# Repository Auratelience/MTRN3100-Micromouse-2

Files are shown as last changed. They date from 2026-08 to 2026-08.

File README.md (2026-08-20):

# MTRN3100 Micromouse

A micromouse that can either be told the maze or made to explore it. Told: an
overhead photo of the deck goes in, a collision-checked path in the firmware's
own `Segment` alphabet comes out, and the robot drives it while localising
against a map exported from the same photo. Explore: the robot is given a start
cell and a goal, maps the maze with its three range sensors, then plans a route
over what it found and races it.

```
                    path-planning/                     firmware/
   maze photo  ->   photo -> lattice -> map        ->  maze_map.h   ->  Arduino
   (.png/.jpg)      map   -> Dubins RRT* -> path        maze_path.h      Nano R4

                                    firmware-sim/
                          the same two headers, driven against a
                          line-by-line Python port of the sketch
```

Six directories, each with its own README:

| directory | what it is | language |
| --- | --- | --- |
| [`firmware/`](firmware/) | the robot. `micromouse.ino` plus the header-only libraries it is built from | C++17, Arduino |
| [`firmware-sim/`](firmware-sim/) | `micromouse.ino`'s control loop with a simulated robot underneath it, and 257 tests over it | Python, stdlib only |
| [`path-planning/`](path-planning/) | photo in, `maze_map.h` and `maze_path.h` out | Python + OpenCV/NumPy/SciPy, via `uv` |
| [`scripts/`](scripts/) | every entry point: `build.sh` compiles the sketch, `build_maze.sh` runs the photo-to-headers pipeline, `export_splash.py` turns the splash art into a bitmap | zsh, Python |
| [`hardware/`](hardware/) | CAD for the printed chassis and the maze wall panels, and the OLED splash art | Bambu Studio, Grasshopper, Aseprite |
| [`notes/`](notes/) | course handouts and working notes. Nothing here is read by any code | PDF, JPEG |

Both scripts take `--help`, run from any directory, and derive their paths from
the repo root rather than the caller's cwd.

## The robot

An Arduino Nano R4 (`arduino:renesas_uno:nanor4`) driving a two-wheel
differential base, with everything but the motors and encoders on one I2C bus.

| part | detail | where it is described |
| --- | --- | --- |
| 2 × DC motor + quadrature encoder | 700 CPR, 31.4 mm effective wheel diameter, 92.5 mm axle | `firmware/micromouse/motor.h`, `constants.h` |
| DRV8835 H-bridge | PWM on `xEN`, direction on `xPH` | `pins.h` |
| MPU6050 IMU | gyro Z only; accelerometer measured and left unused | `imu.h`, `observers.h` |
| 3 × VL6180X ToF | front / left / right, addresses `0x30`–`0x32`, re-addressed at boot over their GPO pins | `lidar.h` |
| SSD1306 OLED 128×64 | a splash through bring-up, then one screen for every task: the map on the left, the run's numbers on the right | `oledDisplay.h`, `oledScreen.h`, `oledSplash.h` |

Pin assignment lives in one place, `firmware/micromouse/pins.h`. Every tunable
number lives in one place, `firmware/micromouse/constants.h`, and each one
carries the reasoning for its value.

The maze is the full-size standard: 180 mm cells, 12 mm panels and posts.

## Getting started

### Flash the robot

Open `firmware/micromouse/micromouse.ino` in the Arduino IDE, or:

```sh
./compile.sh                        # build into firmware/build, ~15s (--help for options)
./compile.sh --flash                # ...and upload it to the connected board, ~11s more
```

`--flash` finds the port by asking `arduino-cli` which one has a board matching
the FQBN on it, so nothing has to be hardcoded; pass `--port /dev/cu.usbmodemXXXX`
to override it. The port is resolved *before* the build, so an unplugged board
fails immediately instead of after a full compile.

`./compile.sh` forwards to `./scripts/build.sh`.

Libraries: Embedded Template Library, Adafruit SSD1306 (and Adafruit GFX),
VL6180X. Which task the sketch builds is one `#define TASK` near the top of
`micromouse.ino` — see [`firmware/README.md`](firmware/README.md) for what each
one does.

### Plan a maze

```sh
./scripts/build_maze.sh 5.png --from 1,1 --to 3,3   # overlay on screen, headers installed
./scripts/build_maze.sh 5.png --no-install          # ...or leave the firmware alone
```

This is the only supported way to produce the pair, because the map and the path
have to be exported against the *same* start pose or the robot localises against
a map offset from the path it is driving. The wrapper exists to enforce that.
Details in [`path-planning/README.md`](path-planning/README.md).

The first run lets `uv` build the environment from `path-planning/pyproject.toml`
(Python ≥ 3.14, OpenCV, NumPy, SciPy).

### Drive it without a robot

```sh
cd firmware-sim
python3 -P run.py --viz --open                # watch it drive the installed headers
python3 -P run.py task34                      # a retained TASK 3.x regression scenario
```

[`firmware-sim/README.md`](firmware-sim/README.md) covers the arguments and what
the sim is and is not a port of.

### Run the tests

The sim's 257 tests, from the repo root:

```sh
python3 -P -c "
import importlib, pathlib, sys, unittest
sys.path.insert(0, '.')
suite = unittest.TestSuite()
for p in sorted(pathlib.Path('firmware-sim/tests').glob('test_*.py')):
    suite.addTests(unittest.defaultTestLoader.loadTestsFromModule(
        importlib.import_module('firmware-sim.tests.' + p.stem)))
sys.exit(not unittest.TextTestRunner().run(suite).wasSuccessful())
"
```

and the planner's own checks:

```sh
cd path-planning
uv run python selftest.py            # Dubins, segments, world, planner
uv run python selftest.py --image    # ...and the CV pass, which needs mazes/1.png
```

No maze photo is tracked, so the `--image` pass needs one supplied — see
[`path-planning/mazes/README.md`](path-planning/mazes/README.md).

**Why `-P`, and why not `unittest discover`.** `firmware-sim/types.py` mirrors
the firmware's `types.h` and so shadows the standard library's `types` module
whenever its directory lands on `sys.path` — which is exactly what running a
script from that directory does. `-P` (or `PYTHONSAFEPATH=1`) keeps it off.
`python3 -m unittest discover -s . -t ..` additionally needs the loader to
accept a namespace package: the directory is called `firmware-sim`, a hyphen is
not a legal identifier, and there is no `__init__.py` to fall back on. CPython
3.11 through 3.14 refuse it with *Start directory is not importable*, hence the
explicit loader above.

## Conventions that cross directory boundaries

**Two frames, two handednesses.** The map is in image convention — +x east, +y
south, origin at the lattice corner — and is left-handed. The robot's frame is
right-handed: **x forward, y left**, theta CCW, origin wherever odometry was last
reset. `path-planning/segments.py::to_firmware` mirrors between them and flips
every `Left`/`Right` as it goes. Anything under `firmware/` is in the robot
frame; anything under `path-planning/` is in the map frame until it is emitted.

The same convention carries into cells: `Direction` in `types.h` has North
stepping +x and West stepping +y, so a route `MazeMapper` produces feeds
`PSPlanner` with no axis or sign fixup in between.

**Units are mm, radians and seconds,** everywhere, including inside the
generated headers.

**`maze_map.h`, `maze_path.h` and `splash_screen.h` are generated.** Do not
hand-edit them; the `snake_case` name is the signal. Re-run `build_maze.sh` for
the first two, which each keep the previous copy as `.bak` beside it: `maze_map.h`
records the photo, the lattice fit RMS and the start pose it was exported
against; `maze_path.h` records the start and goal cells, the turn radius and the
same frame note. `splash_screen.h` is the OLED logo, and `build.sh --flash`
re-exports it from `hardware/Splashscreen.png` on its own.

**Numbers that appear in two languages are mirrored, not shared.**
`firmware/micromouse/constants.h`, `firmware-sim/constants.py` and the geometry
constants in `path-planning/maze_map.py` carry the same values by hand. When the
C++ and the Python disagree, the C++ is right — that is the premise the sim is
built on.

## Known divergences

Real, verified, and worth knowing before trusting a run:

* **The axle offset differs between the firmware and the planner.**
  `AXLE_DIST_FROM_CENTRE` is `20` mm in `firmware/micromouse/constants.h` and in
  `firmware-sim/constants.py`; `AXLE_OFFSET_MM` in `path-planning/rrt_star.py`
  is `25.0`. The planner is therefore clearing corners for a body 5 mm further
  ahead of the axle than the firmware believes it has, which is conservative in
  the direction that matters but means the two are not mirroring the same
  number. The turn-radius bands quoted in `path-planning/README.md` are derived
  from the 25.
* **The sim runs a pose correction gain of `0.2` where the sketch passes `0.1`.**
  Both `task42.h` and `task43.h` build `SensorFusion sf(obs_v, obs_p, 0.1)`;
  `firmware-sim` keeps the `FusionWeights::PoseCorrectionGain` default of `0.2`.
  So a lidar fix is folded in twice as fast in the sim as on the robot. See
  `firmware-sim/README.md`.
* **`FrontLidarObserver` ignores its 57 mm mount offset**
  (`LIDAR_MOUNT_FRONT_X`), in both copies. It writes `pose.x =
  -getReading(Front)`, so the pose it reports is 57 mm short. Fine as a relative
  wall-distance measurement, wrong as a pose. See `firmware-sim/README.md`.
* **No maze photo is tracked.** `.gitignore` excludes `*.png` and `*.jpg`, so
  `path-planning/mazes/` arrives empty from a fresh clone while several scripts
  default to a photo in it — `maze_demo.py` to `mazes/4.png`, and
  `export_map.py`, `bench.py` and `selftest.py --image` to `mazes/1.png`. Supply
  your own and pass it explicitly. See
  [`path-planning/mazes/README.md`](path-planning/mazes/README.md).
* **`scripts/build.sh` still advertises a `lidar` target.** It points at
  `firmware-ds/lidar`, a bring-up sketch that has been deleted from the repo, so
  `./scripts/build.sh lidar` fails. `micromouse` is the only target that builds.

---

MTRN3100 micromouse project — Zimmy Levi (z5587840).

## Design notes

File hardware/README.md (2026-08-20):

# hardware

CAD for the things that get printed: the robot's chassis plate, and the maze wall
panels the deck is built from. Nothing here is built, generated or read by any
code in this repository — it is kept alongside the source so the chassis that the
constants in `firmware/micromouse/constants.h` describe does not live on
somebody's laptop.

| file | format | tracked | opens with |
| --- | --- | --- | --- |
| `Micromouse Lower Frame v2.3mf` | 3MF, Bambu Studio project (~73 KB) | yes | Bambu Studio, Orca Slicer; the mesh alone in any slicer or CAD tool |
| `Wall.3mf` | 3MF, Bambu Studio project (~118 KB) | yes | as above |
| `Wall.gh` | Grasshopper definition (~15 KB) | yes | Grasshopper, inside Rhinoceros |
| `Wall.stl`, `Wall-nolegs.stl` | STL meshes | **no** — `.gitignore` excludes `*.stl` | anything |

Both `.3mf` files are slicer *projects*, not bare meshes: they carry the plate
layout and the print profile as well as the geometry. Re-slice against your own
printer before sending either anywhere.

A `.3mf` is a zip, so the geometry can be pulled out without a slicer:

```sh
unzip -o "Micromouse Lower Frame v2.3mf" -d frame/   # 3D/Objects/*.model is the mesh
```

## Lower frame

The printed chassis plate the motors, board and sensor mounts bolt to. Version 2.

One object, 2160 vertices, bounding box ≈ 82.2 × 84.2 × 24.5 mm. Saved profile:
**Bambu Lab X1E, 0.4 mm nozzle, Bambu PLA Basic, 0.2 mm layers**.

## Wall

The maze panels. One wall part, tiled as 16 instances across three plates, so a
run of the project prints a batch rather than a single piece. The part's mesh
spans 183 × 183 × 85 mm — a cell-pitch footprint, matching the 180 mm cells and
12 mm panels in `constants.h`. Saved profile: **Bambu Lab X1E, 0.4 mm nozzle,
generic PLA, 0.28 mm layers** — a coarser layer height than the frame, since
these are bulk structural prints.

`Wall.gh` is the Grasshopper definition the geometry came from, so the panels are
parametric: change the pitch or the height there and re-bake rather than editing
a mesh. It needs Rhino, and it is binary, so git cannot merge it.

`Wall.stl` is the baked mesh and `Wall-nolegs.stl` the same panel without its
feet. Neither is tracked — re-export them from `Wall.gh` or `Wall.3mf`.

Neither the `.3mf` nor the `.gh` has a plain-text representation, so git cannot
merge any of this. If two people need to change one, take turns.

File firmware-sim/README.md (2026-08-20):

# firmware-sim

`micromouse.ino`'s control loop, with a simulated robot underneath it.

```
python3 run.py                            # drive the installed maze_path.h
python3 run.py --viz --open               # ...and watch it
python3 run.py task34                     # a retained TASK 3.x regression scenario
python3 run.py --plan 5 --from 1,1 --to 4,6   # plan a fresh path first, then drive it
```

There are 257 tests. `unittest discover` cannot load them — see the note below —
so the root [`README.md`](../README.md#run-the-tests) carries the explicit loader
to run them with.

Stdlib only. `--plan` is the one exception and it runs path-planning in
path-planning's own uv environment, not this one.

Two portability notes, both consequences of the directory layout rather than of
the sim. `types.py` mirrors `types.h` and so shadows the standard library's
`types` module on any interpreter that has not already imported it by the time
this directory reaches `sys.path` — if `run.py` dies importing `enum`, run it as
`python3 -P run.py` (or set `PYTHONSAFEPATH=1`). And `unittest discover` has to
accept a namespace package to name a directory with a hyphen in it: CPython 3.11
through 3.14 do not, and answer *Start directory is not importable*. The root
[`README.md`](../README.md#run-the-tests) carries an explicit loader that runs
all 257 tests without either problem.

## What is a port and what is not

Every module named after a header is a line-by-line port of it, method names and
all, so the two can be diffed by eye. **When they disagree, the header is
right** — that is the whole point. Where a port deliberately departs from the
sketch it is a *configuration* choice, never a behavioural one, and each is
listed under [Where the sim departs from the
sketch](#where-the-sim-departs-from-the-sketch).

| module | mirrors | notes |
| --- | --- | --- |
| `constants.py` | `constants.h` | verbatim; derived values stay derived |
| `types.py` | `types.h` | `Segment`, and the `Obstacle`/`Map` layer `LidarObserver` casts into. No `trig<>` LUTs, no `RingBuffer` |
| `kinematics.py` | `kinematics.h` | |
| `control.py` | `control.h` | `PID`, `MotionController` |
| `planners.py` | `planners.h` | all five planners |
| `observers.py` | `observers.h` | including `LidarObserver`'s full Levenberg–Marquardt solve |
| `fusion.py` | `sensorFusion.h` | see below |
| `lidar.py` | `lidar.h` | only the VL6180X's *observable* behaviour: 10 ms period, 2 mm quantisation, the min/max clamps |
| `runner.py` | `setup()` + `loop()` | |
| `scenarios.py` | the sketch's task configurations | `planned` mirrors `task42.h`; `task31`–`task34` are retained regression scenarios. Nothing here ports `task43.h` — the sim has no `MazeMapper` or `MazeRunner` |

Sim-only, with no firmware counterpart: `plant.py` (ground truth — the only
place true state exists), `world.py`, `mapper.py`, `png.py`, `maze_header.py`,
`cli.py`, `viz/`.

`sim.py` and `sim_ps.py` predate the package and are kept as standalone
artefacts; both say so at the top.

## The generated headers

`scripts/build_maze.sh` writes `maze_map.h` and `maze_path.h` and installs
them into `firmware/micromouse/`. `maze_header.py` parses both back, so the
default run is *exactly* what the sketch compiles — same obstacles, same
segments, same frame — with no OpenCV and no re-planning.

Both are exported against one `--from`/`--theta0`, which is why the wrapper
passes the same pair to `maze_demo.py` and `export_map.py`. `--plan` here does
the same thing for the same reason.

Ground truth is built from the map (`MapWorld`), and ranges come from
`Map.cast`, not from the occupancy raster — a 5 mm DDA would put 2.5 mm of
quantisation into every reading, which is the same order as the error the
observer exists to remove. The raster is only for the viewer and for `Mapper`.

`--world-map` points the plant at a *different* header from the one the robot
localises against. That is how you ask what a stale export costs.

## Two things the sim found

**`fusePose` collapsed the pose estimate onto the origin.** `xWeightTotal` and
`yWeightTotal` started at `1.0f` "to represent the Model_Observer's trust", but
`xTotal`/`yTotal` started at `0.0f` — so the model's vote was a vote for the
origin rather than for where dead reckoning said the robot was. A pose source
agreeing *exactly* with dead reckoning still dragged the estimate toward (0, 0)
by `g/(1+t)` of the remaining distance every tick: 17% per control loop at
`t = 0.2`, `g = 0.2`. At 1 kHz the position was pinned within
milliseconds. `theta` escaped it — its numerator accumulates deltas, and the
model's own delta really is zero.

**Fixed**, in `firmware/micromouse/sensorFusion.h` and now mirrored here: all
six totals start at `0.0f`, so the weighted mean is over the pose sources alone
and the result is applied as a correction to dead reckoning rather than as a
replacement for it. `python3 run.py` with no arguments is the header's own
behaviour again, and drives the installed path clean. Two consequences worth
knowing:

- Only the *ratio* of the trusts survives the mean now, not their scale. A lone
  source at `(0.2, 0.2, 0.1)` and the same source at `XYPTrust` land in the same
  place, which is why the `.ino` switching between them changed nothing.
- An axis no source has an opinion on falls through the `<= 0.0f` guard and
  keeps dead reckoning. Under `XYPTrust` (1, 1, 0) that is `theta`, every tick —
  heading on the robot is pure dead reckoning by construction, not by accident.

**`FrontLidarObserver` ignores its mount offset.** It writes `pose.x =
-getReading(Front)`, but the front sensor sits 57 mm ahead of the robot centre
(`LIDAR_MOUNT_FRONT_X`), so the pose it reports is 57 mm short. Visible as the
steady offset in `run.py task32`. Harmless for a relative wall-distance test,
wrong as a pose. Still unfixed everywhere.

## Where the sim departs from the sketch

Two places, both worth re-checking when the `.ino` changes:

**Pose correction gain — a real mismatch, not a deliberate one.** `task42.h` and
`task43.h` both build `SensorFusion sf(obs_v, obs_p, 0.1)`. `scenarios.py` passes
no gain at all, so it takes the `FusionWeights::PoseCorrectionGain` default of
`0.2`: a lidar fix is folded in twice as fast here as on the robot.

This used to be justified. The sketch passed `0`, which makes `fusePose` return
dead reckoning unchanged, so mirroring it would have computed the lidar fix and
multiplied it by zero — every localisation scenario here would quietly have
become a dead-reckoning one, and `0` was read as a debug value left in the
sketch. Now that the sketch passes a real `0.1`, that reasoning is spent and the
`0.2` is simply stale. Pass `0.1` to the `SensorFusion` in
`_wheel_imu_and_lidar_pose_fusion` to close it; expect localisation scenarios to
converge more slowly when you do. `--no-localisation` remains how you ask for
dead reckoning on purpose.

**`task31`–`task34`.** The commented-out 3.1–3.4 blocks these scenarios were
written against have been deleted from the sketch, which now picks between
`task42.h` and `task43.h` with its `TASK` define. They are kept as regression
scenarios, because `DistancePlanner`, `HeadingPlanner`, `PosePlanner` and
`PSPlanner` are all still in `planners.h` and this is the only thing that drives
them end to end. A failure in one is a report about `planners.h`, not about the
`.ino`.

Not a departure so much as a gap, and worth stating: **`task43.h` is not ported.**
The sim has no `MazeMapper`, `MazeRunner` or `MazeWallMap`, so frontier
exploration and localisation against discovered walls are exercised only on the
robot. `planned` mirrors `task42.h`.

## Arguments

`run.py --help` is authoritative. The groups:

- **path and map** — `--path`, `--map`, `--world-map`, `--no-localisation`,
  `--cruise`
- **generate a path first** — `--plan IMAGE`, `--from`, `--to`, `--theta0`,
  `--robot-radius`, `--turn-radius`, `--mode`, `--iters`, `--plan-seed`,
  `--install`, `--verbose`
- **run** — `--loop-hz`, `--max-seconds`, `--start-error X,Y,DEG`,
  `--mm-per-pixel`
- **plant** — `--motor-tau`, `--pwm-deadband`, `--gyro-bias`, `--gyro-noise`,
  `--lidar-noise`, `--enc-error-left/right`, `--seed`. None of these are
  measured; they are knobs, and `plant.py` says so per field.
- **output** — `--viz`, `--port`, `--speed`, `--open`, `--svg`, `--json`,
  `--quiet`

Exit status is 0 when the planner reached the end, 1 when it did not, so a sweep
over seeds or turn radii needs no output parsing:

```sh
for s in 1 2 3 4 5; do
  python3 run.py --plan 5 --plan-seed $s --quiet && echo "seed $s ok"
done
```

`--start-error` puts the robot somewhere `sf.set(Pose{0,0,0})` does not know
about — the error a lidar fix has to find:

```
python3 run.py --no-localisation --start-error 25,15,4   # 39 mm out, stays out
python3 run.py                   --start-error 25,15,4   # 11 mm at the goal
```

Those two numbers are against whatever `maze_path.h` is installed, so they move
whenever the route does — how much of a 29 mm start error the fix recovers
depends on how much wall the route puts in front of the beams. Re-run them rather
than trusting the figures here.

## Why `run.py` and not `python3 -m firmware-sim`

The directory name has a hyphen, which is not a legal Python identifier, so the
package cannot be named in an `import` statement. `run.py` imports it by string
through `importlib`, which has no such restriction. The tests reach it the same
way, via `unittest discover`'s own importer — hence `-t ..` from this directory.

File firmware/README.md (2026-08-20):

# firmware

The robot. One Arduino sketch, `micromouse/micromouse.ino`, and the header-only
libraries it is assembled from.

```sh
../compile.sh                        # build into firmware/build, ~15s
../compile.sh --flash                # ...and upload it to the connected board
../compile.sh --db                   # regenerate compile_commands.json for clangd
../compile.sh --help                 # full usage
```

Build with `compile.sh` rather than calling `arduino-cli compile` directly: it
empties `firmware/build` first, which is what keeps a build at ~15s instead of
the 4+ minutes arduino-cli takes when it re-enters a populated build directory.
`../compile.sh` is a forwarder for `../scripts/build.sh`.

Third-party libraries: **Embedded Template Library** (`etl/`), **Adafruit
SSD1306** and **Adafruit GFX**, **VL6180X** (Pololu). Everything else in
`micromouse/` is local. C++17; `std::array` and `std::variant` are used, but
nothing that allocates — `etl::vector`, `etl::string` and `etl::delegate` stand
in for the heap-using equivalents, and every container has a compile-time
capacity in `constants.h`.

Everything sits in one flat sketch directory because the Arduino build requires
it: headers beside the `.ino`, no include paths, no subfolders that are not
libraries.

## The control loop

`loop()` is five calls, at whatever rate the board manages (`dt` is measured,
not assumed; `MIN_LOOP_DT_S` only rejects a zero-length tick):

```
i2cRepairer.update()      probe the bus, rebuild it if it has wedged
sf.update(dt)             step every observer, fuse -> Pose + Velocity
taskUpdate(pose, dt)      the selected task's planner -> desired Velocity
mc.update(desired, ...)   IK -> per-wheel PID -> PWM
taskRender()              the selected task's display, throttled internally
```

Two of those five are hooks the task header supplies, which is what keeps
`loop()` free of any `#if` — see [Task blocks](#task-blocks).

Two rates are decoupled from that: the OLED refreshes every `OLED_REFRESH_MS`
(≈24 Hz), and the VL6180Xs free-run at `LIDAR_CONTINUOUS_PERIOD_MS` (10 ms), so
`LidarObserver` skips a solve rather than re-solving a reading it has already
seen.

## Modules

| header | owns |
| --- | --- |
| `constants.h` | every tunable number in the project, with the reason for its value |
| `pins.h` | the Nano R4 pin map. `Pin` is a `uint8_t` alias |
| `types.h` | `Pose`, `Vec2D`, `Velocity`, `Segment`, `RingBuffer`, the `Trig<>` LUTs, and the obstacle/`Map` layer the lidar localiser casts rays into |
| `kinematics.h` | differential-drive FK and IK, with the IK scaling both wheels down together when either exceeds `MAXIMUM_WHEEL_ANGULAR_VELOCITY` |
| `motor.h` | `Motor<ID>` — DRV8835 output plus encoder counting: a rising-edge interrupt on channel A, reading B for direction. Templated on ID so each instance gets its own static ISR |
| `control.h` | `PID` (saturating, NaN-guarded) and `MotionController` (velocity → IK → two PIDs → PWM) |
| `planners.h` | the five planners, below |
| `observers.h` | `WheelObserver`, `ImuObserver`, `FrontLidarObserver`, `LidarObserver`, `ModelObserver` |
| `sensorFusion.h` | `SensorFusion` — a trust-weighted blend of velocity sources and pose sources over the dead-reckoning model |
| `lidar.h` | VL6180X driver: bring-up and re-addressing, status decoding, non-blocking reads |
| `imu.h` | raw I2C MPU6050 driver with a rolling average |
| `i2cRepairer.h` | I2C bring-up and runtime recovery |
| `mazeMapper.h` | frontier exploration of an unknown N×N maze, and the shortest route through what the exploration actually saw. Cells only — no sensor, no motor, no pose |
| `mazeRunner.h` | `MazeMapper` closed loop against the robot: `Init → Explore → Plan → Race → Done`, non-blocking, one `update()` per tick |
| `mazeWallMap.h` | a `Map`-shaped view of the mapper's wall bits, so `LidarObserver` can localise against discovered walls. Derives every obstacle on demand and stores nothing |
| `maze_map.h`, `maze_path.h`, `splash_screen.h` | **generated** — see below |

The display is three headers, and one screen serves every task:

| header | owns |
| --- | --- |
| `oledDisplay.h` | the only owner of the SSD1306 — one framebuffer, one `begin()`, and the `OLED_REFRESH_MS` throttle. Also `OLEDView`, the mm → px projection |
| `oledScreen.h` | `OLEDScreen` — the map as *geometry* in a 64 px pane on the left (every panel a line at its own angle, every post and cylinder a filled disc, the route a polyline, the robot a dot and a heading tick), and five rows of values on the right. Templated on the map type, so it draws either `Map<S>` or `MazeWallMap` |
| `oledSplash.h` | `drawSplash()` — the logo from the generated `splash_screen.h`, blitted once during bring-up |

The values pane is the mode, then `X`, `Y` and `T` from the pose, then one
percentage whose meaning travels with its label — `E` for cells explored, `P`
for distance along a route:

```
+---------- 64 px ----------+--- 62 px ---+
| walls as lines, obstacles | EXPL        |  mode
| as filled circles, the    | X    340    |  mm
| route as a polyline, the  | Y    128    |  mm
| robot as a dot and a tick | T    -87    |  deg
|                           | E    42%    |  metric
+---------------------------+-------------+
```

Before any of that, `setup()` calls `drawSplash()` in place of a `clear()`, so
the panel shows the logo for the rest of bring-up and the first `OLEDScreen`
frame in `loop()` overwrites it. There is no splash state to leave and nothing in
`loop()` to gate: the run display is reached by the run starting. A `delay()`
after the call holds it longer.

**The OLED block belongs directly under the I2C bring-up, and moving it is what
breaks the splash.** `display.init()` needs nothing but `Wire`, and the logo is
on screen for exactly as long as the bring-up *below* it takes. Almost all of
that is `imu_obsv.init()`, which spends `IMU_STARTUP_SETTLE_MS` settling and then
a `IMU_CALIBRATION_MS` window averaging the gyro's zero-rate output — 3 s in
which the robot is required to stand still anyway. With the lidar's ~90 ms of
settle delays after it, the splash holds for about 3.2 s and needs no `delay()`
of its own.

It was written at the end of `setup()` first, after both of those, where all that
was left to outlast were two `Serial` prints and `taskBegin()`: the logo was gone
inside ~10 ms and the only visible effect was the `clearDisplay()` inside
`display.init()` — a black blink.

Deliberately, `drawSplash()` does not ask `OLEDDisplay::due()`. That throttle is
*consuming* and opens once per `OLED_REFRESH_MS`, so a lone frame going through
it would be swallowed whenever bring-up had already drawn inside the window — and
the milliseconds of I2C it exists to protect are a cost `loop()` has, not
`setup()`.

Everything on it arrives through an `etl::delegate`, so the screen knows nothing
about `MotionPlanner`, `MazeRunner` or `MazeMapper`. The map extent it fits to
comes from `mapBounds()` in `types.h`, which is a property of the map rather than
of the panel; only the projection that consumes it lives in `oledDisplay.h`.

### Planners

All five expose the same shape: `update(pose, dt) -> Velocity`. Which one is
live is decided by the selected task header — see [Task blocks](#task-blocks).
`MotionPlanner` is what `task42.h` drives; `PSPlanner` is what `task43.h`'s
`MazeRunner` drives, and it drives each grid pose through a `PosePlanner` of its
own. `HeadingPlanner` and `DistancePlanner` are reached only by `firmware-sim`'s
retained 3.x scenarios.

| planner | what it drives to |
| --- | --- |
| `MotionPlanner` | a list of `Segment`s (straights and minor arcs). Feed-forward `curvature × v` plus proportional heading and lateral-error terms; advances a segment at `SEGMENT_ADVANCE_THRESHOLD` of its length. This is the one the generated path targets |
| `PosePlanner` | a single `Pose`: seek the position, then align to the heading. `setHeadingOnly()` for rotations in place |
| `PSPlanner` | a string of grid instructions — `"ffrfllfrlf"` — over 180 mm cells, driving each grid pose through a `PosePlanner` |
| `HeadingPlanner` | one heading, rotating in place |
| `DistancePlanner` | one forward distance, holding heading zero |

### Observers and fusion

`SensorFusion` owns a `ModelObserver` (dead reckoning: integrate the fused
velocity forward) and blends two kinds of source into it.

*Velocity sources* are averaged by trust, per component:

* `WheelObserver` — encoder deltas through the FK. Good `v`, noisy `omega`.
* `ImuObserver` — gyro Z, bias measured over 500 samples at rest in `init()`.
  The accelerometer is read but not integrated; it was too noisy to be useful.

*Pose sources* produce a correction that is folded into dead reckoning at the
gain handed to `SensorFusion` — `0.1` in both task headers, against a
`FusionWeights::PoseCorrectionGain` default of `0.2` — per tick, so a fix nudges
rather than teleports:

* `FrontLidarObserver` — front range as an x measurement. No longer wired by
  either task; `firmware-sim`'s `task32` scenario is the only thing that drives
  it, and it ignores its mount offset (see below).
* `LidarObserver<S>` — the real one. Casts the three beams into `MAZE_MAP`,
  gates each return (incidence angle, residual, implied heading), and runs a
  damped Levenberg–Marquardt solve for `(x, y, theta)` against a prior. The
  prior comes from a delegate you wire to the fused pose:

  ```cpp
  lidar_obsv.setPrior(decltype(lidar_obsv)::PoseFunc::create<fusedPose>());
  ```

  Unwired it falls back to its own last estimate, which is only good for
  bench-testing a single solve. The whole `LIDAR_OBSERVER_*` block in
  `constants.h` documents why each gate is where it is; the prior sigmas in
  particular are load-bearing, because three beams routinely leave one direction
  of pose space unobservable and something has to decide how the correction is
  split between translation and rotation.

## Task blocks

The two current tasks live in `task42.h` and `task43.h`, and `micromouse.ino`
picks one with a single `#define` near the top:

```cpp
#define TASK 43   // 42 -> task42.h, 43 -> task43.h
```

Anything other than 42 or 43 is an `#error`. The sketch itself holds only the
shared hardware — motors, IMU, lidar, `obs_v`, `dt`, the display and the
`MotionController` — plus a `setup()`/`loop()` skeleton with no `#if` in it.
The selected header is included part way down, after the objects it builds on
exist, and supplies the parts that differ:

| | task42.h | task43.h |
| --- | --- | --- |
| the maze is | known — fitted by CV from a photo | unknown; finding it is the exercise |
| pose source | `LidarObserver` over `MAZE_MAP` | `LidarObserver` over `MazeWallMap` |
| motion | `MotionPlanner(10, 0.06, 200)` | `MazeRunner` over `PSPlanner(8, 8)` |
| `taskBegin()` | `#include "maze_path.h"` | `runner.begin()` |
| `taskRender()` | `OLEDScreen` over `MAZE_MAP`, mode `CV` | `OLEDScreen` over `MazeWallMap`, mode `EXPL`/`HOME`/`EXEC` |

Both build `SensorFusion sf(obs_v, obs_p, 0.1)` and wire `setPrior()` in
`setup()`. Those two go together: the observer needs the prior to be worth
anything.

Each builds exactly one `OLEDScreen` and draws it every tick, for every phase
of the run. There is no renderer to select, which is what `OLEDDisplay::due()`
being *consuming* asks for: it hands the refresh window to its first caller, so
two renderers sharing a tick would silently starve whichever asked second.

4.3's mode is the one place the display reads a phase that `MazeRunner` does not
have. The leg back to the start cell is rule 3 of `MazeMapper::planMove` and sits
inside `Explore`, so `MazeMapper` exposes `homing()` and `homeProgress()` and
`screenMode()` folds them in — otherwise the screen would report `EXPL` for the
whole return trip.

The whole of 4.3's configuration is four lines at the top of `task43.h`:

```cpp
constexpr uint8_t MAZE_SIZE = 5;        // cells per side
mazeMapper::Cell startCell = {0, 0};
Direction startHeading     = North;
mazeMapper::Cell goalCell  = {2, 4};
```

`MAZE_SIZE` sizes every templated class below it, and cost grows as N². Change
those four and nothing else has to move.

Both headers declare the same names — `lidar_obsv`, `obs_p`, `sf`,
`fusedPose()` and the three `task*()` hooks — which is what lets `setup()` and
`loop()` be written once. They are alternatives rather than layers because
`MotionPlanner`'s segment array alone is about 10 kB: 4.2 links at 48% of RAM,
4.3 at 33%.

Earlier assessment tasks are no longer in the sketch. `firmware-sim`
reproduces each by name (`run.py task31` …); for reference, they were:

| block | fusion | planner | setup |
| --- | --- | --- | --- |
| TASK 3.1 | wheels + gyro | `MotionPlanner(10, 0.06)` | three hand-written segments — a 1 m straight, an arc, a return |
| TASK 3.2 | + `FrontLidarObserver` as an x source | `DistancePlanner(3, 0.06)` | `setTarget(200.0f)` — hold 200 mm off the wall |
| TASK 3.3 | wheels + gyro | `HeadingPlanner(5)` | `setTarget(PI/2)` |
| TASK 3.4 | wheels + gyro | `PSPlanner(10, 5)` | `addInstructions("ffrfllfrlf")` |

## Generated headers

`maze_map.h` and `maze_path.h` are written by `scripts/build_maze.sh`, and are
used by `task42.h` only — 4.3 discovers its maze instead.
**Do not edit them by hand.** `maze_map.h` records the photo it was fitted from,
the lattice fit RMS and the obstacle counts; `maze_path.h` records the start and
goal cells and the turn radius. Both record — critically — the start pose they
were exported against:

```
// Robot frame: x forward, y left, mm. The origin is the start pose
// [270.0, 270.0] mm heading 90 deg in map coordinates (auto), which is where a
// freshly reset odometry frame reads (0, 0, 0).
```

Both files must come from the same photo *and the same `--from`/`--theta0`*, or
the robot localises against a map offset from the path it is driving. That is
the entire reason `build_maze.sh` exists rather than two separate invocations.

`maze_map.h` is `constexpr`, so the map lives in flash and costs no RAM.
`maze_path.h` is not a header in any real sense — it is a run of
`planner.appendSegment(...)` statements, `#include`d *inside* `setup()`.

`.bak` beside each is the previous installed copy, kept by the wrapper.

`splash_screen.h` is separate from those two and unrelated to the maze:
`scripts/export_splash.py` writes it from `hardware/Splashscreen.png` as a
`constexpr uint8_t[1024]` in `drawBitmap`'s own layout — row-major, 16 bytes per
row, MSB leftmost, a set bit lit — so it is in flash and costs no RAM either.
`scripts/build.sh --flash` re-exports it before every compile it is going to
upload, because a stale logo is invisible until the panel lights up. Its
`snake_case` name is the same signal the maze headers carry: **generated, do not
edit by hand.** The hand-written half is `oledSplash.h`, which is what a change
to how the splash is *drawn* should touch.

## Things that will bite

* **The I2C bus wedges.** The renesas_uno core's `Wire` never recovers on its
  own: a timeout does not abort the in-flight FSP transfer, so one slave holding
  SDA low kills every device until the bus is manually clocked out and the
  driver reopened. `I2CRepairer` probes every 250 ms and rebuilds after three
  consecutive failures. Do not shorten `I2C_WIRE_TIMEOUT_US` below one SSD1306
  framebuffer chunk (≈5.7 ms at 400 kHz) or transfers get abandoned mid-flight.
* **The three VL6180Xs boot at the same address.** `LIDAR::init()` pulls all
  three low over their GPO pins, then brings them up one at a time and
  re-addresses each. GPO is driven **low or left as an input, never driven high**
  — the sensor pulls itself to 2.8 V and 5 V destroys it (`pins.h`).
* **Encoders are calibrated per wheel.** `ENC_RAD_PER_REV_LEFT`/`RIGHT` were
  hand-measured; readings are scaled so one turn reads exactly 2π. Re-measure
  after any drivetrain change.
* **Turn radius comes in bands.** Up to 26 mm, or 73–182 mm, and nothing
  between — the geometry is worked through in `path-planning/README.md`, and the
  bands are narrower than the axle-centred arithmetic suggests because the body
  rides ahead of the axle and swings wider through every turn. The obvious
  "slightly tighter than a cell" 70 mm cannot clear a pivot post.
* **The axle offset is not the same number here as in the planner.**
  `AXLE_DIST_FROM_CENTRE` is `20` mm; `AXLE_OFFSET_MM` in
  `path-planning/rrt_star.py` is `25.0`, and the bands above are derived from the
  25. Conservative in the direction that matters, but the two are not mirroring
  each other — see the root README's known divergences.
* **`Serial` in the loop costs milliseconds.** `loop()` is kept free of it;
  `setup()` prints freely because nothing is timing-critical yet. Add a print to
  the loop only while you are actually debugging, and take it out again.

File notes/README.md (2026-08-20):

# notes

Reference material: the course handouts the project is built against, and
working notes taken while building it. Nothing here is built, generated or read
by any code in this repository.

| file | what it is |
| --- | --- |
| `MTRN3100_Micromouse.pdf` | the assignment specification — the tasks the firmware's `TASK` define selects between |
| `Micromouse_Kit_Information.pdf` | the supplied kit: parts, pinouts and the board's own documentation |
| `Lidar Maths.jpeg` | hand-worked derivation of the lidar localisation geometry, behind `LidarObserver` in `firmware/micromouse/observers.h` |

**None of it is tracked.** `.gitignore` excludes `notes/*.pdf` and
`notes/*.jpeg`, so this directory arrives holding only this README. The handouts
come from the course, not from here.

CAD for the physical robot is not in this directory — it is in
[`hardware/`](../hardware/).

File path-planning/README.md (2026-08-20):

# path-planning

Overhead photo of the maze in, a path the firmware can drive out.

```
python maze_demo.py                        # photo -> map -> path -> appendSegment() calls
python maze_demo.py --from 4,4 --to 7,7 --emit path.h
python selftest.py --image                 # geometry, planner and CV checks
python bench.py                            # success rate and cost over a set of trips
```

These run under `uv` from this directory. To produce the firmware's header pair,
do not call `maze_demo.py` and `export_map.py` yourself — use
[`scripts/build_maze.sh`](../scripts/README.md), which gives both the same start
pose. Its per-run outputs (`map_<stem>.h`, `path_<stem>.h`, the overlay) land
here.

## Pipeline

| module | what it owns |
| --- | --- |
| `maze_grid.py` | finds the blue post caps and fits the 180 mm lattice, the nadir, the pitch and the camera height |
| `maze_map.py` | walls per bond, **posts per node**, the deck polygon, free-standing cylinders |
| `rrt_star.py` | collision model in world mm, straight-line RRT\*, and **Dubins RRT\*** |
| `dubins.py` | the six Dubins words, vectorised |
| `segments.py` | the firmware's `Segment` in Python, plus the C++ emitter |
| `maze_demo.py` | end to end, with an overlay and the pasteable output |

## Output: straights and arcs

`plan_dubins` searches in `(x, y, theta)` and steers with Dubins curves, so every
tree edge is already a sequence of straights and minimum-radius arcs — the exact
alphabet of `Segment` in `firmware/micromouse/types.h`. Nothing is smoothed
afterwards, so the curve that was collision checked is the curve that gets
driven.

```
segments   17 (7 straight, 10 arc at r=30 mm), 1960 mm; hold cruiseVelocity <= 346 mm/s
           firmware-representable, joins continuous

planner.appendSegment(Segment({0.01f, 0.00f}, {288.41f, 0.13f}));
planner.appendSegment(Segment({288.41f, 0.13f}, {291.24f, 0.00f}, 1.0f / 30.00f, Segment::Direction::Right));
```

Two details of the firmware contract that the emitter enforces, both of which
fail silently if ignored:

* **Minor arcs only.** `centrePreCalcRadiusAndMidpoint` rebuilds an arc's centre
  from its chord, which recovers the *minor* arc. A turn over 180 deg would come
  back as a different circle, so turns are split at 90 deg.
* **Handedness.** The map is image convention (+x east, +y south) and is
  left-handed; the robot's frame is right-handed (x forward, y left). `to_firmware`
  mirrors and flips every `Left`/`Right` with it, then re-origins the path onto
  the robot's start pose so it can be pasted against a fresh odometry frame.

`--scale k` resizes the emitted path, and only the emitted path, on the way out:
endpoints and arc radii multiply by `k`, curvature divides by it, turn directions
stand. The map, the clearance report and the overlay stay life size, so the
guarantee above stops holding — at anything but 1, the curve that was collision
checked is not the curve that gets driven. Scaling up is the sharper edge: past
1000 mm a radius falls under `STRAIGHT_TOLERANCE` and the firmware drives the
chord instead of the arc, so `check` runs again on the scaled path and reports it.
`build_maze.sh --scale` passes the factor to the planner alone and warns that the
`maze_map.h` beside it is still life size.

`selftest.py` checks both against an independent computation, including a
deliberately unrepresentable 270 deg arc that `segments.check` must reject.

The demo defaults to `mazes/4.png`; the tests and benchmark pin `mazes/1.png` so
their numbers stay comparable, and the headers currently installed in the
firmware were exported from `mazes/5.png`.

**No photo is tracked.** `.gitignore` excludes `*.png` and `*.jpg`, so `mazes/`
arrives empty from a fresh clone and every one of those defaults is missing —
supply your own and pass it explicitly. The numbers quoted throughout this file
are against the working set the figures were measured on (`1.png`, `4.png`,
`5.png`), which is why they will not reproduce from a bare checkout. See
[`mazes/README.md`](mazes/README.md) for what a usable photo needs.

## Posts

A post is an obstacle, not just a landmark, and the two failure modes are
opposite:

* **Posts with no walls.** A node can carry a post with no panel on any of its
  four bonds — an isolated stump on open floor. It never appears in
  `wall_segments_mm`, so a wall-only collision model drives straight through it.
  `mazes/1.png` has 10 of them.
* **No posts.** A node can equally carry nothing. `detect_posts` scores every
  node independently rather than assuming the lattice is populated, so a maze
  with gaps — or with no posts at all — maps correctly. `MazeWorld` likewise
  accepts an empty wall list, for a maze that is posts on bare floor.

Detection uses two independent pieces of evidence. The blue cap is what
`maze_grid` already segmented to fit the lattice; the fallback, for caps the
tight HSV gate drops, is the wall detector's darkness measurement swept along
the post's own leaning silhouette. The threshold is self-calibrating at half the
median score of the nodes `maze_grid` accepted. On `mazes/1.png` that finds 93
of 100 nodes — 80 by cap, 13 by silhouette — and the seven it rejects are the
chamfered corners, which have no post.

`prune_posts` then drops claims another obstacle already covers: nodes off the
deck (a reflection off the frame can add a whole phantom lattice row — `4.png`
fits 10x11 nodes for that reason) and nodes under a fitted cylinder, whose dark
body is what scored. Neither weakens the model: a post further outside the deck
than its own radius is unreachable behind the keep-in constraint, and a post
inside a cylinder is inside a strictly larger disc. That leaves 84 obstacles on
`1.png`. The ASCII dump marks a bare node `.`:

```
+---.   +   +   +   +   +---+   .---+
|       |                   |   |   |
.   +   +   +---+   +---+   +---+---.
```

Posts also join the occluder mask, so a post whose cap was missed is not
reported as a 15 mm cylinder.

## Two numbers worth knowing before you tune

**Turn radius comes in bands, not a range.** A 90 deg turn tangent to two cell
centrelines misses the pivot post by `|hypot(R, 25) - sqrt(2)|90-R||` — the
`hypot` because the body orbits the turn centre 25 mm off the axle, which is
what the arc has to fit. For a 40 mm robot that has to clear 53.5 mm, leaving
`R <= 26 mm` or `73 <= R <= 182 mm`. The obvious "a bit tighter than a cell"
choice of 70 mm sits in the gap and cannot turn a corner at all.

Of the two bands only the small one is searchable. A 90 mm arc is the textbook
micromouse turn — centred exactly on the post — but it is clear only if entered
within a few mm of the centreline and square to it, which a sampler essentially
never hits: at R = 90 the tree spread over two thirds of the maze and never once
connected. The 30 mm default turns comfortably from anywhere across the corridor
and costs speed, not safety: `sqrt(a r)` caps a 30 mm arc at 346 mm/s against the
robot's 392 mm/s ceiling.

The default now sits just outside the lower band, which reached 30.6 mm before
the axle offset was accounted for. That bounds the textbook corner, not the
planner — a centreline-tangent turn is one arc out of a continuum and the search
turns from wherever it likes, which is the whole reason 30 mm beat 90 mm. It does
cost the tightest corners some tries; `--turn-radius 25` buys the margin back at
316 mm/s.

**The corner cells are not reachable.** The deck's chamfer leaves cell (0,1) an
escape slot about 1 mm wide for a 40 mm robot. The straight-line planner threads
it — that is what its 1.2 mm minimum clearance was — but no bounded-curvature
path fits, at any radius, even with the padding set to zero. That is geometry,
not search: if you need to start there, shrink `--r` or `extra_clearance_mm`
and check the reported clearance yourself.

## The axle is not in the middle

A differential drive turns about its axle, so the axle is the point a Dubins
curve tracks and the point odometry reports — but on this chassis it sits 25 mm
behind the middle, and it is the middle that hits things. `AXLE_OFFSET_MM` in
`rrt_star.py` is that number; set it to 0 for a centred robot.

The two are genuinely different curves. The body rides 25 mm ahead of every
planned pose, and around a turn it orbits the same centre at `hypot(R, 25)` —
39 mm on a 30 mm arc, nearly a third wider — so an arc that clears for the axle
can still put a corner into a post. The alternative, a single disc of
`40 + 25 = 65 mm` about the axle, is sound but costs 25 mm of clearance
everywhere on a deck whose tightest doorways already have under 2 mm.

So `MazeWorld` splits its queries by what they are handed:

| query | takes |
| --- | --- |
| `clearance`, `is_free`, `motion_valid` | the **body centre** |
| `pose_clearance`, `pose_free`, `curve_valid` | an **axle pose**, and works the body out |

`plan_dubins` searches over axle poses and uses the pose queries throughout;
`plan` has no heading to speak of and plans the body centre directly. The
overlay's red marks and the `clearance` line are read off the body too, so what
the picture shows is where the robot actually is.

## Collision checking

Straight edges are checked exactly (segment-segment and segment-circle
distances). Curved edges are checked by sampling at `ds` of arc length and
requiring clearance above `ds/2`, which is conservative rather than approximate:
every point of the curve is within `ds/2` of arc length from a sample, and
Euclidean distance never exceeds arc length. `ds` defaults to 2.5 mm, small
enough not to wall off the tight doorways this deck has. `selftest.py` checks
20x-denser ground truth against it and expects zero leaks.

That proof is about the body's curve, so it is the body that has to be sampled
at `ds` — and it covers `hypot(R, 25) / R` more arc than the axle for the same
swept angle. `dubins.sample_poses` takes the offset and tightens the angular
step by exactly that factor; handing `curve_valid` axle samples at `ds` while
the body swings wider would leave the proof about nothing in particular.

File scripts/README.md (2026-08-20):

# scripts

Every entry point in the repo. All three take `--help` and all three derive
their paths from the repo root, so they can be run from any directory and do not
care about the caller's cwd. The two `.sh` are zsh; `export_splash.py` is a
`uv run --script` file that carries its own dependency block.

| script | what it does |
| --- | --- |
| `build.sh` | compiles an Arduino sketch into `build/` beside it |
| `build_maze.sh` | maze photo in, overlay on screen and `maze_map.h`/`maze_path.h` installed into the firmware |
| `export_splash.py` | splash art in, `splash_screen.h` installed into the firmware |

```sh
./scripts/build.sh                    # micromouse, the default target, ~15s
./scripts/build.sh --flash            # ...and upload it, ~11s more
./scripts/build.sh --db               # compile_commands.json only, for clangd
./scripts/build_maze.sh 5 --from 1,1 --to 3,3
./scripts/export_splash.py            # re-export the OLED splash bitmap
```

`./compile.sh` at the repo root is a forwarder to `build.sh`, kept because that
is the command in the READMEs and in `firmware/.clangd`'s own comment.

## build.sh

`micromouse` (`firmware/micromouse`) is the default target and the only one that
builds; it builds into `build/` beside the sketch, which is where that tree's
`.clangd` pins its compilation database.

> `--help` also lists a `lidar` target, pointing at `firmware-ds/lidar`. That
> bring-up sketch has been deleted from the repo, so the target is dead and
> `./scripts/build.sh lidar` fails on the missing directory.

A target, if given, must be the **first** argument, so that a bare word appearing
later is read as a passthrough flag's value rather than as a mistyped target —
`--warnings all` works, and `./scripts/build.sh bogus` is an error rather than
something `arduino-cli` gets to be confused by.

Everything that is not one of the script's own options is passed straight
through to `arduino-cli compile` — never to the upload step.

### Flashing

`--flash` uploads after a successful build. The port is not hardcoded: the
script asks `arduino-cli board list` which serial ports have a board matching
the FQBN on them, and requires **exactly one** match. Zero matches and two
matches are both errors that name what was seen, because silently picking one of
two boards is how you flash the wrong device. `--port /dev/cu.usbmodemXXXX`
skips detection entirely.

`--flash` also re-runs [`export_splash.py`](#export_splashpy) before the
compile, so the logo the board boots with is always the current art. A plain
build skips it and compiles the committed header as it stands, which keeps the
fast inner loop free of `uv`.

Three ordering choices worth knowing: the port is resolved *before* the build, so
an unplugged board costs a second rather than a full compile; the splash is
re-exported after that check but before the compile, so a missing board still
fails first and the regenerated header is the one that gets built; and
`--db --flash` is rejected up front, since `--db` skips code generation and
leaves no binary to upload. Detection is the only thing in this script that
needs `python3`, and it runs only on the `--flash` path.

The Nano R4 uploads over DFU, so the port re-enumerates during the flash; that
is normal and `arduino-cli` reports the new port when it finishes.

The build directory is **emptied at the start of every run**, which is what
keeps a build at ~15s instead of the 4+ minutes `arduino-cli` takes when it
re-enters a populated one. The reasoning, and why nothing is lost by doing it,
is in the comment at the top of the script. `build/.cache` is preserved so
clangd does not reindex every time.

## build_maze.sh

The wrapper exists to enforce one coupling: `maze_demo.py` and `export_map.py`
must be given the *same* `--from`/`--theta0`/`--r`, because the exported map and
the exported path are both re-origined onto that start pose. Give them different
ones and the robot localises against a map offset from the path it is driving.

Although the script lives here, everything it reads and writes belongs to
[`path-planning/`](../path-planning/): `mazes/`, the `uv` project it runs under,
and the per-run `map_<stem>.h`/`path_<stem>.h`/overlay it leaves behind. That is
deliberate — `.gitignore` covers those outputs as `path-planning/*.h`, a rule
that does not reach into `scripts/`. The installed headers go to
`firmware/micromouse/`, each keeping the previous copy as `.bak`.

## export_splash.py

`hardware/Splashscreen.png` — a two-tone 128x64 export of
`hardware/Splashscreen.aseprite` — becomes `firmware/micromouse/splash_screen.h`,
a `constexpr uint8_t[1024]` in the layout `Adafruit_GFX::drawBitmap` reads.
`oledSplash.h` blits it once from `setup()`, so it holds the panel through
bring-up until the first `OLEDScreen` frame overwrites it.

Unlike `build_maze.sh` this needs nothing from `path-planning/`: it imports no
local modules and declares `pillow` in a PEP 723 block, so `uv run --script`
resolves it on its own. `build.sh --flash` runs it that way.

Two things are hard errors rather than something the script fixes up — art that
is not exactly 128x64, and art holding any value between black and white. Both
mean re-exporting from Aseprite, because rescaling or thresholding here would put
pixels on the robot that nobody drew, and the panel has no grey to render with.
Nothing is written unless the bytes actually change, so an unchanged re-export
does not restamp the header's mtime and send `arduino-cli` rebuilding.

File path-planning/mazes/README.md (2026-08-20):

# mazes

Input photos. One overhead shot of the deck per file; everything else in
`path-planning/` is derived from one of these.

**Nothing here is tracked.** `.gitignore` excludes `*.png` and `*.jpg`, so this
directory arrives holding only this README, while several scripts default to a
photo in it — `maze_demo.py` to `mazes/4.png`, and `export_map.py`, `bench.py`
and `selftest.py --image` to `mazes/1.png`. Supply your own photo and pass it
explicitly:

```sh
./scripts/build_maze.sh 5.png --from 1,1 --to 3,3   # from the repo root
uv run python maze_demo.py mazes/5.png             # from path-planning/
```

`selftest.py --image` additionally sweeps *every* file in this directory for its
post-masking check, so anything dropped in here has to be a fittable maze photo,
not a screenshot or a crop. Files OpenCV cannot decode are skipped; files it can
decode but cannot fit will fail the sweep.

## What a usable photo has to have

`maze_grid.py` calibrates itself from the photo, but it calibrates from
*something*, and these are the parts that are not negotiable:

* **Blue post caps, in focus and lit.** The lattice fit is a clustering of the
  blue mask; the HSV gate is `(80, 55, 75)`–`(110, 255, 255)` and a minimum blob
  area of 6 px. Fewer than 8 blobs and the fit refuses to start.
* **An overhead view, but not a perfectly vertical one.** The posts must project
  as visible streaks converging on a nadir — that convergence is what yields the
  camera height and the pitch. A dead-flat orthographic render has nothing to
  fit.
* **The whole deck in frame,** including the chamfered corners. The deck polygon
  is what keeps the planner inside the maze, and phantom lattice rows from a
  reflection off the frame are pruned by it.
* **Enough resolution to resolve a post cap.** ~50 px of lattice pitch is what
  the current photos give and what the "no morphological closing" decision in
  `detect_blobs` is calibrated against.

Free-standing cylinders and posts with no adjoining wall are both handled — see
[`../README.md`](../README.md) — so a maze does not have to be tidy, only
photographed properly.

## Naming

`<n>.png` or `<n>.jpg`. `build_maze.sh` accepts any of `5`, `5.png` or
`mazes/5.png`, and names its outputs after the stem (`map_5.h`, `path_5.h`,
`map_5_overlay.png`), so keep stems distinct.

A fit is only reproducible against the exact photo it was made from, and since
none is tracked, that photo has to be kept somewhere outside git — the numbers in
[`../README.md`](../README.md) do not reproduce without it. `maze_map.h` in
`firmware/micromouse/` names the photo it was fitted from in its header comment,
which is the only record in the repo of which one that was.

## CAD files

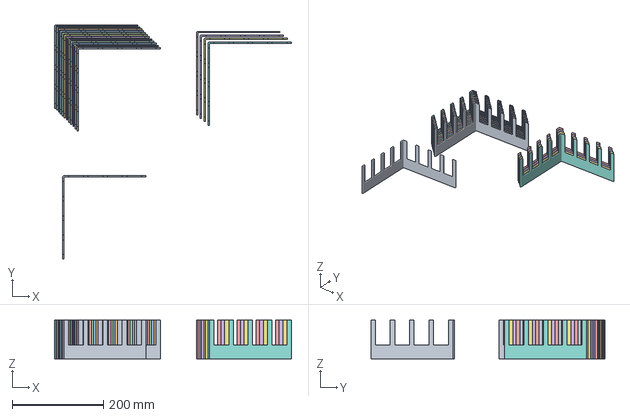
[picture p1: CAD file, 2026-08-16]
hardware/Wall.3mf
519.8 x 513.8 x 85.0 mm
Wall.stl x 17

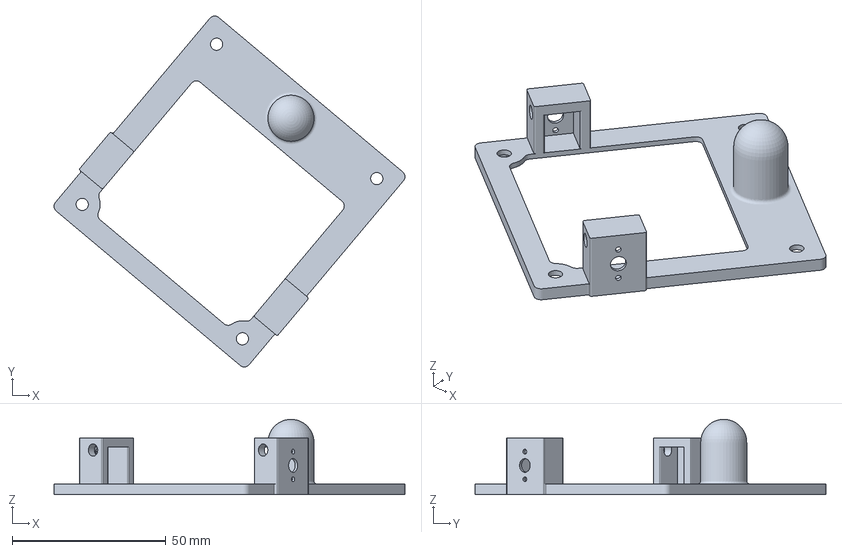
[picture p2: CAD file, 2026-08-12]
hardware/Micromouse Lower Frame v2.3mf
114.2 x 114.2 x 24.5 mm

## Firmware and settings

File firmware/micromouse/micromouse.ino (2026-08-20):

#include <Arduino.h>
#include <Wire.h>
#include <array>

#include "constants.h"
#include "control.h"
#include "pins.h"
#include "i2cRepairer.h"
#include "imu.h"
#include "kinematics.h"
#include "lidar.h"
#include "motor.h"
#include "observers.h"
#include "oledDisplay.h"
#include "oledSplash.h"
#include "sensorFusion.h"
#include "types.h"

// WHICH TASK TO BUILD
//
// 42 -- task42.h: drives the pre-computed maze_path.h route through
//       MotionPlanner and localises against the exported maze_map.h.
// 43 -- task43.h: explores the maze, plans a route over what it found and
//       races it, localising against the walls it discovered.
//
// The two are alternatives, not layers: MotionPlanner's segment array alone is
// about 10 kB of RAM. Everything below this line is shared, and the selected
// header is included further down, once the objects it builds on exist.
#define TASK 43

#if TASK != 42 && TASK != 43
#error "TASK must be 42 or 43"
#endif

Motor<0> leftMotor(
    WHEEL_RADIUS,
    MOT_1_DIR,
    MOT_1_PWM,
    MOT_1_ENC_A,
    MOT_1_ENC_B,
    ENC_CPR,
    false,
    ENC_SCALE_LEFT
);

Motor<1> rightMotor(
    WHEEL_RADIUS,
    MOT_2_DIR,
    MOT_2_PWM,
    MOT_2_ENC_A,
    MOT_2_ENC_B,
    ENC_CPR,
    true,
    ENC_SCALE_RIGHT
);

Kinematics kinematics(WHEEL_RADIUS, AXLE_LEN);

// Add fixer for I2C channels which can break under high frequency interrupts and OLED buffer delays
I2CRepairer i2cRepairer(I2C_SDA, I2C_SCL, LIDAR_FRONT_ADDRESS);

WheelObserver wheel_obsv(leftMotor, rightMotor, kinematics);

IMU imu;
ImuObserver imu_obsv(imu);

LidarSensor frontLS(LIDAR_FRONT_ADDRESS, TOF_3_GPO);
LidarSensor leftLS(LIDAR_LEFT_ADDRESS, TOF_1_GPO);
LidarSensor rightLS(LIDAR_RIGHT_ADDRESS, TOF_2_GPO);
LIDAR lidar(std::array<LidarSensor*, 3>{&frontLS, &leftLS, &rightLS});

// The velocity side of the fusion is the same either way. The pose side is not
// -- it is the map the observer localises against that differs -- so obs_p and
// the SensorFusion built from both live in the task header.
//
// The wheels alone. The gyro used to be blended in here as an omega, at four
// times the wheels' weight in heading, which is what made theta depend on the
// control loop's dt: ModelObserver integrates fused omega against whatever the
// loop period happened to be, and an OLED frame makes that period jump by an
// order of magnitude with no gyro sample taken across the gap. It is a pose
// source now -- see ImuObserver -- and integrates on the sensor's own clock.
//
// So current.omega, which is what MotionController closes its per-wheel PIDs
// on, is now wheel-derived end to end. That is what those PIDs were written
// for; it does also mean the loop no longer sees body rotation directly, so
// wheel slip is rejected by the pose estimate rather than by the controller.
const std::array<VelocitySource, 1> obs_v = {{
    {&wheel_obsv, FusionWeights::DefaultVTrust}
}};

// Loop period, seconds. At file scope rather than local to loop() so a task
// header or a trace can read the rate the control loop is actually running at.
float dt = 0;

OLEDDisplay display;

// The task, included here rather than with the headers above because it builds
// on lidar, obs_v, dt and display. Both headers declare the same names, so
// setup() and loop() below are written once and need no #if of their own.
#if TASK == 42
#include "task42.h"
#else
#include "task43.h"
#endif

// kd injects noise since loop speed means minimum α = dω/dt is 9 rad/s
MotionController mc(leftMotor, rightMotor, kinematics, 10.0f, 3.0f, 0.0f);

unsigned long previous_time = 0;
unsigned long current_time = 0;

void setup() {
    Serial.begin(115200); // DIAGNOSTIC: was 9600
    delay(1000);
    Serial.println("Beginning setup:");

    Serial.print("Initialising I2C...");
    i2cRepairer.begin();
    Serial.println("\b\b\b [OKAY]");

    // Straight after the bus and before everything slow, which is the whole
    // point: display.init() needs nothing but Wire, and the splash is only
    // on screen for as long as the bring-up *below* it takes. Down at the end
    // of setup(), where this used to sit, the only things left to outlast were
    // two Serial prints and taskBegin() -- so the logo was overwritten by the
    // first loop() frame inside ~10 ms and all that showed was the clear.
    //
    // What makes it readable now is imu_obsv.init(), which is not a settle
    // delay but a 3 s measurement: IMU_STARTUP_SETTLE_MS then a
    // IMU_CALIBRATION_MS window averaging the gyro's zero-rate output. With the
    // lidar's ~90 ms on top, the logo holds for about 3.2 s, so it needs no
    // delay() of its own -- it is showing during time the robot was already
    // going to spend standing still.
    Serial.print("Initialising OLED...");
    if (!display.init()) {
        Serial.println("\b\b\b [OLED INIT FAILED]");
    } else {
        drawSplash(display);
        Serial.println("\b\b\b [OKAY]");
    }

    Serial.print("Initialising Motors...");
    leftMotor.init();
    rightMotor.init();
    Serial.println("\b\b\b [OKAY]");

    Serial.print("Initialising IMU Observer (P)...");
    if (!imu.init(IMU::GyroScale::DPS_1000, IMU::AccelScale::G_4, IMU::LowPassFrequency::HZ_44)) {
        Serial.println("\b\b\b [MPU6050 INIT FAILED]");
    } else {
        imu_obsv.init();
        if (!imu_obsv.ready()) {
            Serial.println("\b\b\b [IMU OBSERVER INIT FAILED]");
        } else {
            Serial.println("\b\b\b [OKAY]");
        }
    }

    Serial.print("Initialising Lidar Observer (P)...");
    if (!lidar.init()) {
        Serial.println("\b\b\b [VL6180X INIT FAILED]");
    } else {
        lidar_obsv.setPrior(decltype(lidar_obsv)::PoseFunc::create<fusedPose>());
        Serial.println("\b\b\b [OKAY]");
    }

    // Seeds every observer that holds an absolute pose, ImuObserver's heading
    // included, so it has to run whatever the lidar did. It used to sit inside
    // the branch above, which was harmless only while nothing on the pose side
    // integrated anything.
    sf.set(Pose{0, 0, 0});

    Serial.print("Loading goal...");

    // NOTE THAT X-AXIS IS FORWARDS: Y-AXIS IS LEFT!!!

    taskBegin();

    previous_time = micros();
    Serial.println("Setup complete!");
}

void loop() {
    current_time = micros();
    dt = (current_time - previous_time) / 1000000.0f;

    if (dt <= MIN_LOOP_DT_S) return;

    i2cRepairer.update();

    sf.update(dt);
    Pose pose = sf.estimate.pose();
    Velocity current = sf.estimate.velocity();
    Velocity desired = taskUpdate(pose, dt);
    mc.update(desired, current, dt);

    taskRender();

    // DIAGNOSTIC: gyro read failures and bus recoveries, rate limited so the
    // report cannot itself stall the loop it is measuring.
    {
        static unsigned long reported = 0;
        static unsigned long last_report_ms = 0;
        const unsigned long failures = imu.failures();
        if (failures != reported && millis() - last_report_ms >= 200) {
            Serial.print(F("imu dropped "));
            Serial.print(failures - reported);
            Serial.print(F(" reads (total "));
            Serial.print(failures);
            Serial.print(F("), fifo losses "));
            Serial.print(imu.fifoLosses());
            Serial.print(F(", i2c recoveries "));
            Serial.println(i2cRepairer.recoveries());
            reported       = failures;
            last_report_ms = millis();
        }
    }

    // DIAGNOSTIC: FIFO samples per control cycle, which is the check on
    // CONTROL_LOOP_NOMINAL_HZ. Capped at a few reports rather than left
    // running: the figure is a cumulative mean and settles within the first
    // couple, and a periodic Serial write is a few ms of exactly the loop
    // stall this whole path exists to stop mattering. Delete freely.
    {
        static unsigned long last_rate_report_ms = 0;
        static uint8_t rate_reports = 0;
        if (rate_reports < 5 && millis() - last_rate_report_ms >= 2000) {
            Serial.print(F("imu "));
            Serial.print(imu_obsv.samplesPerUpdate(), 2);
            Serial.print(F(" samples/cycle at "));
            Serial.print(IMU_SAMPLE_RATE_HZ);
            Serial.print(F(" Hz (CONTROL_LOOP_NOMINAL_HZ "));
            Serial.print(CONTROL_LOOP_NOMINAL_HZ);
            Serial.println(F(")"));
            last_rate_report_ms = millis();
            ++rate_reports;
        }
    }

    previous_time = current_time;
}

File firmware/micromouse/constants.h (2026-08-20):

// Micromouse Constants
//
// Zimmy Levi z5587840

#pragma once
#include <Arduino.h>

constexpr uint8_t MAZE_CORNER_CROP = 1;

// MATH
constexpr float PI_TWO  = PI / 2.0f;
constexpr float PI_FOUR = PI / 4.0f;

// Resolution of the atan/acos lookup tables in trig<> (see types.h).
constexpr size_t TRIG_LUT_SIZE = 256;

// WHEEL & KINEMATICS
// Effective rolling diameter (mm). test implies ~31.4 effective
constexpr float WHEEL_DIAMETER = 31.4f;
constexpr float WHEEL_RADIUS   = WHEEL_DIAMETER / 2.0f;
constexpr int ENC_CPR          = 700;

// Per-wheel encoder calibration. Hand-measured angularDisplacement() for
// exactly one wheel revolution (rad), 2026-07-17. Readings are scaled by
// TWOPI / measured so a full revolution reads exactly 2π.
constexpr float ENC_RAD_PER_REV_LEFT    = 6.04f;
constexpr float ENC_RAD_PER_REV_RIGHT   = 6.18f;
constexpr float ENC_SCALE_LEFT          = TWO_PI / ENC_RAD_PER_REV_LEFT;
constexpr float ENC_SCALE_RIGHT         = TWO_PI / ENC_RAD_PER_REV_RIGHT;
constexpr float AXLE_LEN                = 93.5;
constexpr uint8_t AXLE_DIST_FROM_CENTRE = 20;

constexpr uint8_t MAXIMUM_WHEEL_PWM            = 255;
constexpr float MAXIMUM_LATERAL_ACCELERATION   = 4;  // m/s²
constexpr float MAXIMUM_WHEEL_ANGULAR_VELOCITY = 25; // rad/s

// CONTROL LOOP
// Floor on a usable loop period. A guard against dividing by a dt of zero when
// loop() re-enters before micros() has moved, and nothing more -- it is not the
// period the loop runs at, and it is four orders of magnitude below it.
constexpr float MIN_LOOP_DT_S = 0.000005f; // 5 μs

// Rate loop() actually runs at, excluding the OLED frames. The IMU's sample
// rate is derived from this (see IMU_SAMPLE_RATE_DIVIDER), so it wants to be
// measured rather than hoped for -- the sketch prints observed samples per
// cycle for exactly that purpose, and a figure far from 1 means this is wrong.
//
// Being wrong costs granularity, not accuracy: summing the FIFO integrates
// exactly whatever it holds, whatever rate it was filled at.
constexpr unsigned long CONTROL_LOOP_NOMINAL_HZ = 300;

// MOTION
constexpr long PATH_SEGMENTS_MAX_LEN         = 256;
constexpr float STRAIGHT_TOLERANCE           = 0.001f;
constexpr float MAXIMUM_FORWARD_VELOCITY     = WHEEL_RADIUS * MAXIMUM_WHEEL_ANGULAR_VELOCITY;
constexpr float MAXIMUM_ANGULAR_ACCELERATION = 20.0f; // rad/s²
constexpr float STD_TOL                      = 1e-6f;
constexpr float STD_DIST_TOL                 = 2.0f;
// Position error at which PSPlanner stops translating and starts aligning
// with the target heading.  The larger deadband prevents lidar/odometry
// noise near a cell centre from delaying the turn handoff.
constexpr float PS_POSITION_TOL              = 8.0f;
// constexpr float STD_ANG_TOL                  = 0.02f;
constexpr float STD_ANG_TOL                  = 0.05f;

constexpr float SEGMENT_ADVANCE_THRESHOLD    = 0.995f;

// Fraction of the wheel speed limit an arc's feedforward is allowed to spend,
// leaving the rest for MotionPlanner's heading and lateral terms.
//
// On an arc the planner asks for omega = curvature * v, so the outer wheel runs
// at v (1 + curvature * AXLE_LEN / 2) / WHEEL_RADIUS. Left at cruise that is
// four or five times the wheel limit on a tight arc, and Kinematics::IK scales
// both wheels by one factor to fit -- which preserves the v : omega ratio, so
// the turn is still driven at its own radius, but the feedback terms are scaled
// down by the same factor and arrive with almost no authority. Capping v so the
// feedforward alone fits inside this fraction is what gives them room: the
// remaining 1 - margin is theirs, about 1.7 rad/s of correction on a 10 mm arc.
constexpr float TURN_ENVELOPE_MARGIN         = 0.8f;

// How far behind an arc's start a position still reads as "not started"
// (Segment::arcProgress), rather than as having come round past the end.
//
// A handover is a distance, not an angle: the straight feeding an arc lets go
// within a few mm of its start, and that slop subtends more angle the tighter
// the arc, so this is carried in mm and converted with the curvature. Kept
// small deliberately -- too large and a robot that has come round the back of
// the circle reads as "not started" and can never satisfy
// SEGMENT_ADVANCE_THRESHOLD, which strands it on that segment; too small and a
// slightly early handover reads as past the end and the arc is skipped. A cut
// corner and a robot that never leaves the corner are not equal costs.
constexpr float ARC_BEHIND_START_TOL_MM      = 5.0f;

// MAZE
// Cells per side lives in task43.h, next to the MazeRunner and MazeWallMap
// instances it sizes: 4.3 is the only task that builds a MazeMapper.
//
// Physical size of one grid cell, mm. Full-size Micromouse uses 180mm,
// half-size 168mm. Shared by the path factory and the instruction runner.
constexpr float MAZE_CELL_SIZE = 180.0f;
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

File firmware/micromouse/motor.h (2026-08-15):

// Motor.hpp
// Header-only library due to use of templates
//
// Zimmy Levi z5587840

#pragma once

#include <Arduino.h>

#include "pins.h"

#pragma GCC push_options
#pragma GCC optimize("O2")

class BaseMotor {
    public:

    virtual void init()                          = 0;
    virtual void forward(uint8_t speed)          = 0;
    virtual void backward(uint8_t speed)         = 0;
    virtual void move(int16_t speed)             = 0;
    virtual void stop()                          = 0;
    virtual long count()                         = 0;
    virtual float linearDisplacement()           = 0;
    virtual float angularDisplacement()          = 0;
    virtual void setAngularDisplacement(float a) = 0;
    virtual void setLinearDisplacement(float d)  = 0;
};

// Implements controls for a simple DC motor over a
// DRV8835 motor driver.
//
// Usage: Motor<0> leftMotor(...);
//        Motor<1> rightMotor(...);
//
// Variables intending to use Motor type should use BaseMotor instead
template <unsigned char ID>
class Motor : public BaseMotor {
    public:

    Motor(
        float wheelRadius,
        Pin direction,
        Pin pwm,
        Pin encoderA,
        Pin encoderB,
        int countsPerRevolution,
        bool reverse,
        float encoderScale = 1.0f
    ) :
        wheelRadius(wheelRadius),
        phase(direction),
        enable(pwm),
        countsPerRevolution(countsPerRevolution),
        encoderA(encoderA),
        encoderB(encoderB),
        encoderCount(0),
        reverse(reverse),
        encoderScale(encoderScale),
        encoderB_port(nullptr),
        encoderB_mask(0){}

    // Sets the pinMode for the two motor pins
    //
    // Side effects: modifies pinModes for pins at this.phase and .enable
    void init() override {
        pinMode(phase, OUTPUT);
        pinMode(enable, OUTPUT);
        pinMode(encoderA, INPUT_PULLUP);
        pinMode(encoderB, INPUT_PULLUP);

        encoderB_port = portInputRegister(digitalPinToPort(encoderB));
        encoderB_mask = digitalPinToBitMask(encoderB);

        instance = this;

        // Automatically bind the hardware interrupt
        attachInterrupt(digitalPinToInterrupt(encoderA), Motor<ID>::readEncoderISR, RISING);
    }

    // Turns the motor forwards
    //
    // forward(0) is equivalent to this.stop()
    // speed should be in range [0, 255]
    void forward(uint8_t speed) override {
        if (reverse) {
            digitalWrite(phase, HIGH);
        } else {
            digitalWrite(phase, LOW);
        }
        analogWrite(enable, speed);
    }

    // Turns the motor backwards
    //
    // backward(0) is equivalent to this.stop()
    // speed should be in range [0, 255]
    void backward(uint8_t speed) override {
        if (reverse) {
            digitalWrite(phase, LOW);
        } else {
            digitalWrite(phase, HIGH);
        }
        analogWrite(enable, speed);
    }

    // Combines forward and backwards into a single -255 to 255 range.
    void move(int16_t speed) override {
        if (speed < 0) {
            backward(static_cast<uint8_t>(abs(speed)));
        } else {
            forward(static_cast<uint8_t>(speed));
        }
    }

    // Stops the motor
    void stop() override {
        analogWrite(enable, 0);
    }

    // mm
    float linearDisplacement() override {
        return angularDisplacement() * wheelRadius;
    }

    // rad
    float angularDisplacement() override {
        long countCopy;
        noInterrupts();
        countCopy = encoderCount;
        interrupts();

        // Returns angular displacement of the wheel (in rad), corrected by
        // the per-wheel calibration scale
        return encoderScale * TWO_PI * static_cast<float>(countCopy) /
               static_cast<float>(countsPerRevolution);
    }

    long count() override {
        long countCopy;
        noInterrupts();
        countCopy = encoderCount;
        interrupts();
        return countCopy;
    }

    // rad
    void setAngularDisplacement(float a) override {
        long targetCount = static_cast<long>(
            (a / (encoderScale * TWO_PI)) * static_cast<float>(countsPerRevolution)
        );

        noInterrupts();
        encoderCount = targetCount;
        interrupts();
    }

    // mm
    void setLinearDisplacement(float d) override {
        float circumference     = TWO_PI * wheelRadius;
        float targetRevolutions = d / circumference;
        long targetCount        = static_cast<long>(
            (targetRevolutions / encoderScale) * static_cast<float>(countsPerRevolution)
        );

        noInterrupts();
        encoderCount = targetCount;
        interrupts();
    }

    private:

    static inline Motor<ID>* instance = nullptr;

    // direction pin
    const Pin phase;

    // pwm pin
    const Pin enable;

    const Pin encoderA;
    const Pin encoderB;

    const int countsPerRevolution;

    volatile long encoderCount;

    // mm
    const float wheelRadius;

    const bool reverse;

    // Per-wheel calibration: multiplies raw encoder-derived angle so a full
    // revolution reads exactly 2π.
    const float encoderScale;

    const volatile uint16_t* encoderB_port;
    uint16_t encoderB_mask;

    static void readEncoderISR() {
        if (instance != nullptr) instance->readEncoder();
    }

    void readEncoder() {
        if (!(*encoderB_port & encoderB_mask)) {
            if (reverse) {
                ++encoderCount;
            } else {
                --encoderCount;
            }
        } else {
            if (reverse) {
                --encoderCount;
            } else {
                ++encoderCount;
            }
        }
    }
};

#pragma GCC pop_options

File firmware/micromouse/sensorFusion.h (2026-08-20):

// Sensor Fusion
//
// Zimmy Levi z5587840

#pragma once

#include <Embedded_Template_Library.h>
#include <etl/vector.h>
#include <etl/span.h>
#include <etl/algorithm.h>

#include "types.h"
#include "observers.h"
#include "constants.h"

#pragma GCC push_options
#pragma GCC optimize("O2")

struct ObserverVTrust {
    float vTrust;
    float omegaTrust;
};

struct ObserverPTrust {
    float xTrust;
    float yTrust;
    float thetaTrust;
};

namespace FusionWeights {
// How much of a pose observer's correction is taken per fusion cycle, per
// axis. Split because the two axes are now corrected by different sensors with
// very different standing: position comes from three lidar beams against a map,
// heading from a gyro integrated on its own clock.
//
// Position stays low. A lidar fix is a least-squares solve against a map that
// may be wrong -- MazeWallMap holds only the walls found so far -- and taking
// a fifth of it per cycle averages several solves before the estimate has
// moved far, so one bad association drags nothing very far.
//
// Heading is high, because there is nothing to average against. ImuObserver is
// the only source weighted for theta, and the dead reckoning it corrects is
// wheel rotation through an AXLE_LEN that was never calibrated for turning --
// the worse of the two, not a second opinion. At 0.8 the fused heading is
// effectively the gyro's, with the wheels contributing only a transient, which
// is the intent.
//
// Both are per cycle, not per second, so the time constant they imply scales
// with the loop rate: 0.8 at ~300 Hz settles in about 4 ms, 0.2 in about 17 ms.
constexpr float PositionCorrectionGain = 0.2f;
constexpr float ThetaCorrectionGain    = 0.8f;

    constexpr ObserverPTrust DefaultPTrust = ObserverPTrust{1, 1, 1};
    constexpr ObserverPTrust ThetaPTrust   = ObserverPTrust{0, 0, 1};
    constexpr ObserverPTrust XYPTrust      = ObserverPTrust{1, 1, 0};
    constexpr ObserverPTrust XPTrust       = ObserverPTrust{1, 0, 0};
    constexpr ObserverPTrust YPTrust       = ObserverPTrust{0, 1, 0};

    constexpr ObserverVTrust DefaultVTrust = ObserverVTrust{1, 1};
    constexpr ObserverVTrust VVTrust       = ObserverVTrust{1, 0};
    constexpr ObserverVTrust OmegaVTrust   = ObserverVTrust{0, 1};
}

// Combines velocity and pose observers to provide combined estimates
struct VelocitySource {
    ObserverV* observer;
    ObserverVTrust trust = FusionWeights::DefaultVTrust;
};

struct PoseSource {
    ObserverP* observer;
    ObserverPTrust trust = FusionWeights::DefaultPTrust;
};

class SensorFusion {
    public:

    class estimate {
        public:

        estimate(const SensorFusion& sf) : sf(sf) {}

        Pose pose() const {
            return sf.fusedPose;
        }

        Velocity velocity() const {
            return sf.fusedVelocity;
        }

        private:

        const SensorFusion& sf;
    };

    // Minimum 1 velocity observer and 0 pose observers
    SensorFusion(
        etl::span<const VelocitySource> velocitySrcs,
        etl::span<const PoseSource> poseSrcs = {},
        float positionCorrectionGain         = FusionWeights::PositionCorrectionGain,
        float thetaCorrectionGain            = FusionWeights::ThetaCorrectionGain
    ) :
        estimate(*this),
        modelObserver(
            ModelObserver::VelocityFunc::create<SensorFusion, &SensorFusion::getFusedVelocity>(
                *this
            )
        ),
        fusedVelocity({0, 0}),
        fusedPose({0, 0, 0}),
        positionCorrectionGain(positionCorrectionGain),
        thetaCorrectionGain(thetaCorrectionGain) {
        const size_t nv = etl::min(velocitySrcs.size(), velocitySources.max_size());
        for (size_t i = 0; i < nv; ++i)
            velocitySources.push_back(velocitySrcs[i]);

        const size_t np = etl::min(poseSrcs.size(), poseSources.max_size());
        for (size_t i = 0; i < np; ++i)
            poseSources.push_back(poseSrcs[i]);
    }

    const estimate estimate;

    void set(Pose p) {
        fusedPose = p;
        modelObserver.set(p);
        for (auto& src : poseSources)
            src.observer->set(p);
    }

    void set(Velocity v) {
        fusedVelocity = v;
        for (auto& src : velocitySources) {
            if (src.observer->ready()) src.observer->set(v);
        }
    }

    void update(float dt) {
        for (auto& src : velocitySources)
            src.observer->update(dt);

        fusedVelocity = fuseVelocity();
        modelObserver.update(dt);
        fusedPose = modelObserver.estimate();

        if (!poseSources.empty()) {
            bool any_ready = false;
            for (auto& src : poseSources) {
                if (src.observer->ready()) {
                    src.observer->update(dt);
                    any_ready = true;
                }
            }
            if (any_ready) {
                fusedPose = fusePose(fusedPose);
                modelObserver.set(fusedPose);
            }
        }
    }

    private:

    Velocity getFusedVelocity() const {
        return fusedVelocity;
    }

    Velocity fuseVelocity() const {
        float vWeightTotal = 0.0f, omegaWeightTotal = 0.0f;
        float vTotal = 0.0f, omegaTotal = 0.0f;

        for (const auto& src : velocitySources) {
            if (!src.observer->ready()) continue;

            Velocity velocityEstimate = src.observer->estimate();
            const ObserverVTrust& t   = src.trust;

            vWeightTotal += t.vTrust;
            omegaWeightTotal += t.omegaTrust;
            vTotal += t.vTrust * velocityEstimate.v;
            omegaTotal += t.omegaTrust * velocityEstimate.omega;
        }

        return Velocity{(vWeightTotal <= 0.0f ? fusedVelocity.v : vTotal / vWeightTotal),
            (omegaWeightTotal <= 0.0f ? fusedVelocity.omega : omegaTotal / omegaWeightTotal)};
    }

    Pose fusePose(const Pose &dead_reckoned) const {
        float xWeightTotal = 0.0f, yWeightTotal = 0.0f, dthetaWeightTotal = 0.0f;
        float xTotal = 0.0f, yTotal = 0.0f, dthetaTotal = 0.0f;

        for (const auto& src : poseSources) {
            if (!src.observer->ready()) continue;

            Pose correction         = src.observer->estimate();
            const ObserverPTrust& t = src.trust;

            float dtheta = wrapAngle(correction.theta - dead_reckoned.theta);

            xWeightTotal += t.xTrust;
            yWeightTotal += t.yTrust;
            dthetaWeightTotal += t.thetaTrust;

            xTotal += t.xTrust * correction.x;
            yTotal += t.yTrust * correction.y;
            dthetaTotal += t.thetaTrust * dtheta;
        }
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

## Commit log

2026-08-12 Zimmy z5587840
    Restructured repository to include python path planning code.
    [Micromouse Lower Frame v2.3mf]
2026-08-12 docs: add repository and per-directory READMEs
    Adds a root README covering the whole pipeline (photo -> path-planning ->
    generated headers -> firmware, with firmware-sim driving the same headers),
    the hardware, a quickstart per component, the frame/unit conventions that
    cross directory boundaries, and the divergences between the three copies of
    the firmware headers.
    New READMEs for the directories that had none:
    - firmware/ control loop, module table, the five planners, the
    observer/fusion stack, the TASK blocks, generated headers
    - firmware-ds/ what the lidar bring-up sketch is for, and the one header
    that has drifted from firmware/micromouse/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
2026-08-15 Zimmy z5587840
    1a. Merged mazeMapper.h which wasn't included in this repository.
    b. Fixed bugs, coherency, coupling, and styling issues in mazeMapper.h
    2. Streamlined scripts
    3. Updated wheel calibration constants.
    [Micromouse Lower Frame v2.3mf, Wall.3mf]
2026-08-16 Zimmy z5587840 Task 4.3 Working
    [Wall.3mf]
2026-08-16 Zimmy z5587840 Added axle offset to path planning
2026-08-18 Zimmy z5587840 removed dead code. 4.2 stabilised
    [constants.h, mazeMapper.h, mazeRunner.h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]
2026-08-18 Zimmy z5587840 stabilised IMU noise when the loop is held up by OLED rendering by using the MPU6080's onboard buffer.
    [constants.h, mazeMapper.h, mazeRunner.h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]
